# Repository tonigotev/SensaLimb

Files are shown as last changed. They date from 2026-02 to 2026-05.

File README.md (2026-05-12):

# SensaLimb

Smart arm prosthesis project.

## ML Model (Latest Recommended): Toro Ossaba Conv1D

Use this model family as the current default:

- Model family folder: `ML/models/conv1d_angle_toro_ossaba`
- Dataset folder (required): `ML/datasets/Toro Ossaba`
- Training script: `ML/train/train_conv1d_angle_toro_ossaba.py`

## 1) Install ML dependencies

From the repository root (PowerShell):

```powershell
python -m pip install --upgrade pip
python -m pip install -r requirements-ml.txt
```

## 2) Download and extract the Toro Ossaba dataset (required)

Dataset source:

- https://zenodo.org/records/7946782

Extract location must be exactly:

- `ML/datasets/Toro Ossaba`

Important extraction rule:

- After extraction, your `.txt` dataset files must be inside `ML/datasets/Toro Ossaba/...` (subject subfolders).
- Do **not** leave the files nested one level too deep (for example, avoid `ML/datasets/Toro Ossaba/Toro Ossaba/...`).

Quick check (PowerShell):

```powershell
Get-ChildItem "ML/datasets/Toro Ossaba" -Recurse -Filter *.txt | Select-Object -First 5 FullName
```

## 3) Install/extract the Toro Ossaba trained model files

If you received model files as a zip/archive, extract them into:

- `ML/models/conv1d_angle_toro_ossaba`

Expected model artifacts in the selected run folder:

- `model.keras`
- `model.tflite`
- `model_int8.tflite` (optional but recommended for embedded use)
- `meta.json`

Example expected path pattern:

- `ML/models/conv1d_angle_toro_ossaba/<run_name>/model.tflite`

If your extraction creates an extra folder level, move files so that the run folder directly contains `meta.json` and model files.

## 4) Run the model (inference/validation)

Pick your run folder (example):

```powershell
$MODEL_DIR = "ML/models/conv1d_angle_toro_ossaba/seed9_20260117_034451_884"
```

### A. Compare float vs int8 model outputs

```powershell
python ML/tools/compare_tflite_models.py --model-dir "$MODEL_DIR" --input-root "ML/datasets/Toro Ossaba" --samples 50
```

### B. Generate prediction-vs-true plots

```powershell
python ML/tools/plot_tflite_pred_vs_true.py --model-dir "$MODEL_DIR" --input-root "ML/datasets/Toro Ossaba" --samples 2000
```

Output images are saved in the same run folder:

- `pred_vs_true_float.png`
- `pred_vs_true_int8.png`

## 5) (Optional) Train a new Toro Ossaba model run

```powershell
python ML/train/train_conv1d_angle_toro_ossaba.py --use-file-split --movement all --emg-source filtered --angle-history-sec 0.1 --tflite-int8 --seed 9 --run-name seed9_new
```

This creates a new run folder under `ML/models/conv1d_angle_toro_ossaba`.

## Common setup mistakes

- Dataset extracted to wrong folder (must be `ML/datasets/Toro Ossaba`).
- Extra nested folder after extraction.
- Model archive extracted to wrong location.
- Missing `model.tflite` / `meta.json` in selected run folder.

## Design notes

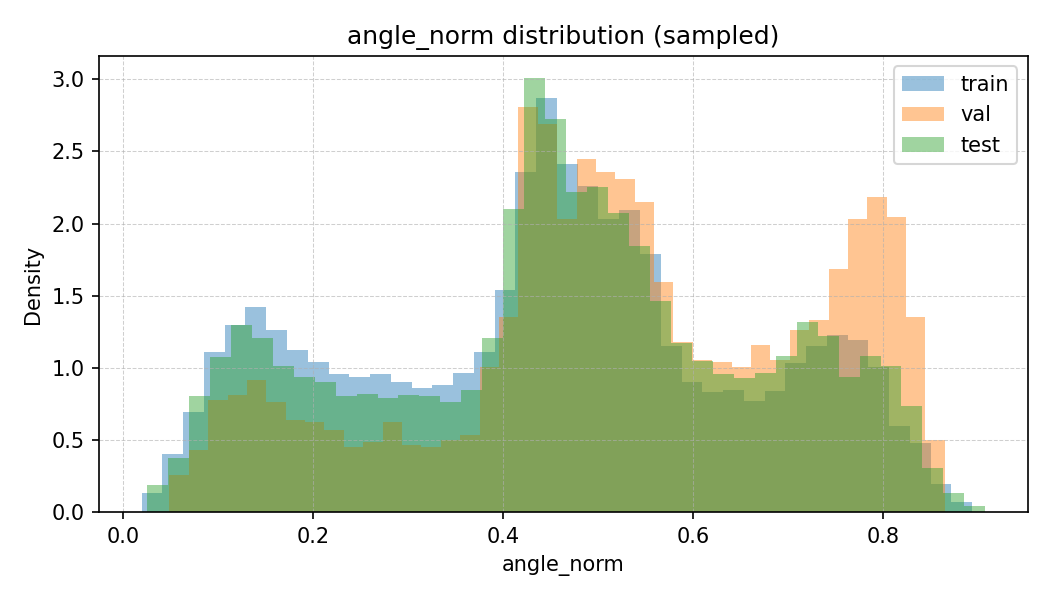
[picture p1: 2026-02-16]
ML/models/conv1d_angle_toro_ossaba/seed2_20260117_113150_814/angle_histograms.png

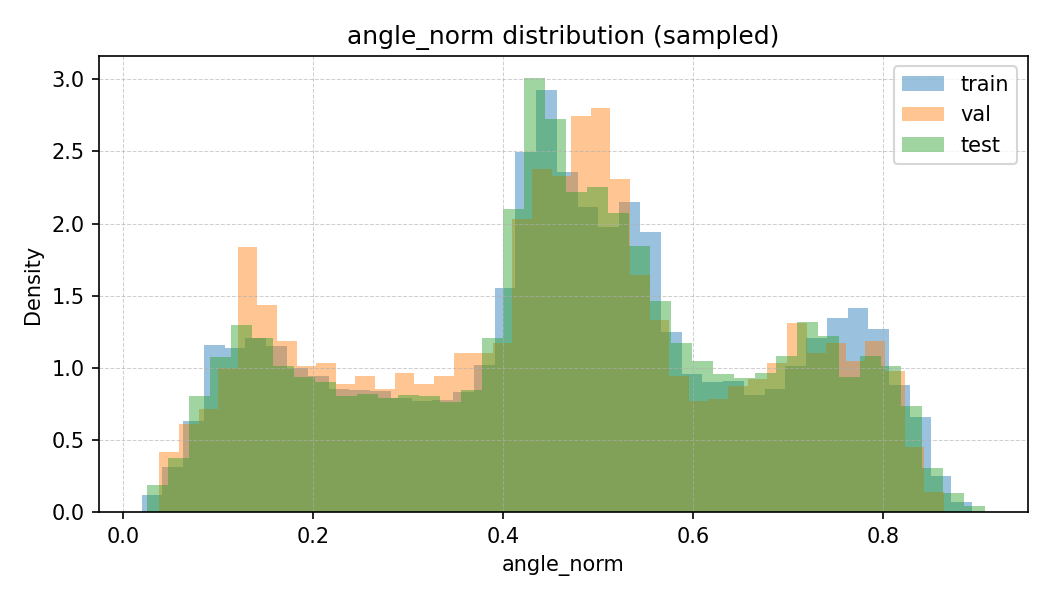
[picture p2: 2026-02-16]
ML/models/conv1d_angle_toro_ossaba/seed7_20260117_034451_861/angle_histograms.png

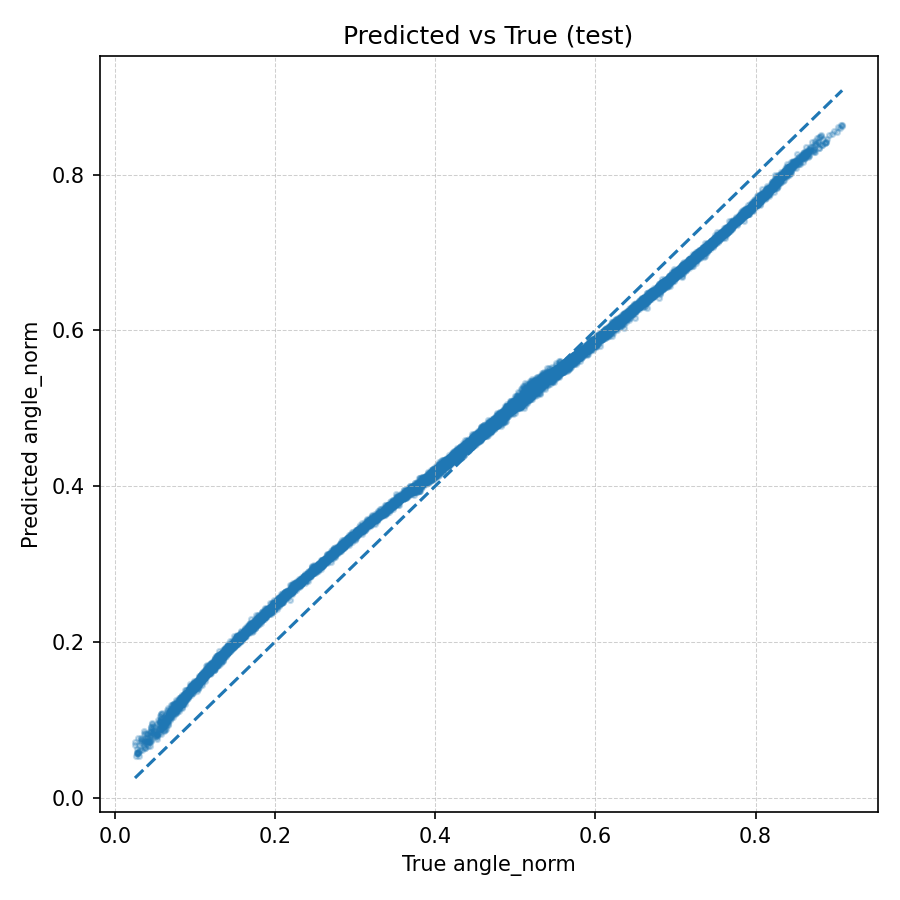
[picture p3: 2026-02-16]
ML/models/conv1d_angle_toro_ossaba/seed1_20260117_034451_773/pred_vs_true.png

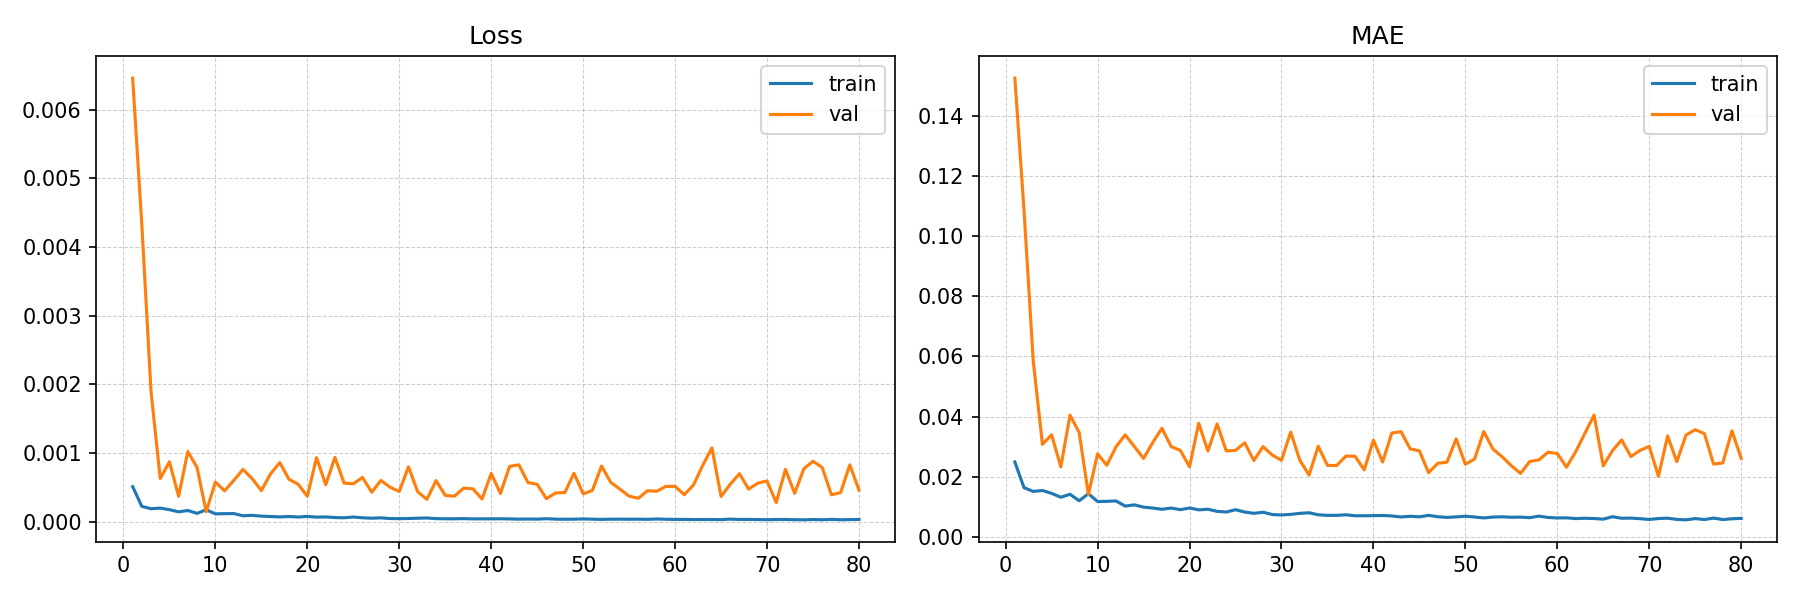
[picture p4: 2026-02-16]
ML/models/conv1d_angle_toro_ossaba/seed3_20260117_045953_614/training_curves.png

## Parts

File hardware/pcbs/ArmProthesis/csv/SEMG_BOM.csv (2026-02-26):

Reference | Value | Footprint | Qty | LCSC
VR1 | 100k | Potentiometer_THT:Potentiometer_Bourns_3296W_Vertical | 1 | C48084
U5 | LME49726MY | OP AMPS:LME49726MY | 1 | C128880
U4 | INA326 | Package_SO:MSOP-8_3x3mm_P0.65mm | 1 | C179740
U3 | LME49726MY | OP AMPS:LME49726MY | 1 | C128880
U2 | DNP | EMG:EMG_Snap_4mm | 1
U1 | DNP | EMG:EMG_Snap_4mm | 1
R12 | 10k | Resistor_SMD:R_0402_1005Metric | 1 | C25744
R11 | 1M | Resistor_SMD:R_0603_1608Metric | 1 | C22935
R10 | 1k | Resistor_SMD:R_0402_1005Metric | 1 | C106235
R9 | 10k | Resistor_SMD:R_0402_1005Metric | 1 | C25744
R8 | 1k | Resistor_SMD:R_0402_1005Metric | 1 | C106235
R6 | 249k | Resistor_SMD:R_0402_1005Metric | 1 | C226368
R5 | 1k | Resistor_SMD:R_0402_1005Metric | 1 | C106235
R4 | 1k | Resistor_SMD:R_0402_1005Metric | 1 | C106235
R3 | 2k | Resistor_SMD:R_0402_1005Metric | 1 | C60488
R2 | 10M | Resistor_SMD:R_0603_1608Metric | 1 | C7250
R1 | 10M | Resistor_SMD:R_0603_1608Metric | 1 | C7250
J4 | DNP | Connectors:DIN_Male_1PIN_1.5mm | 1
J3 | Conn_01x03_Pin | Connector_JST:JST_GH_SM03B-GHS-TB_1x03-1MP_P1.25mm_Horizontal | 1 | C514175
J2 | DNP | Connectors:DIN_Male_1PIN_1.5mm | 1
C11 | 1uF | Capacitor_SMD:C_0603_1608Metric | 1 | C15849
C10 | 1uF | Capacitor_SMD:C_0603_1608Metric | 1 | C15849
C9 | 1uF | Capacitor_SMD:C_0603_1608Metric | 1 | C15849
C8 | 1uF | Capacitor_SMD:C_0603_1608Metric | 1 | C15849
C7 | 1uF | Capacitor_SMD:C_0603_1608Metric | 1 | C15849
C6 | 1uF | Capacitor_SMD:C_0603_1608Metric | 1 | C15849
C3 | 330nF | Capacitor_SMD:C_0402_1005Metric | 1 | C47118439
C2 | DNP | Capacitor_SMD:C_0603_1608Metric | 1
C1 | 10uF | Capacitor_SMD:C_0402_1005Metric | 1 | C6119763

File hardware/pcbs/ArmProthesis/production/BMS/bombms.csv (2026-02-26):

Designator | Footprint | Quantity | Value | LCSC Part #
C1, C6, C7, C9 | 0603 | 4 | 1uF | C15849
C10 | 0402 | 1 | 1uF | C14445
C11 | 1206 | 1 | 10uF | C105197
C12 | 0402 | 1 | 100nF | C110251
C13, C14 | 0603 | 2 | 12pF | C346206
C3, C4, C5 | 0603 | 3 | 0.1uF | C14663
D1, D3, D4 | D_SOD-523 | 3 | 1N4148WT | C232841
D2 | 0603 | 1 | BLUE | C282129
J1 | AMASS_XT60PW-M_1x02_P7.20mm_Horizontal | 1 | XT60-M | C98732
J2 | AMASS_XT60PW-F_1x02_P7.20mm_Horizontal | 1 | XT60-F | C428722
J4 | JST_GH_SM03B-GHS-TB_1x03-1MP_P1.25mm_Horizontal | 1 | Conn_01x03 | C514175
Q1, Q2 | TRANS_BSC014N04LSIATMA1 | 2 | BSC014N04LSIATMA1 | C2934854
R1 | 2512 | 1 | 5m | C22385263
R10, R9 | 0603 | 2 | 1M | C22935
R11 | 0402 | 1 | 120k | C93945
R12 | 0402 | 1 | 1k | C11702
R13, R2, R3, R5, R6, R7, R8 | 0402 | 7 | 100 | C106232
R16 | 0402 | 1 | 10k | C60490
R17, R18, R19 | 0402 | 3 | 4.7k | C25900
R4 | 0402 | 1 | 100k | C25741
SW1, SW2, SW3 | SW_SPST_B3U-3000P | 3 | SW_Push | C963349
U2 | BQ76905RGRR | 1 | BQ76905RGRR | C22394458
U3, U4 | JST_GH_SM02B-GHS-TB_1x02-1MP_P1.25mm_Horizontal | 2 | JST-GH | C189893
U5 | PinHeader_2x05_P2.54mm_Horizontal | 1 | PIN-HEADER | C492433
U6 | TSSOP-20_4.4x6.5mm_P0.65mm | 1 | STM32C011F6Px | C5456198
Y1 | NX3215SA-32.768K-STD-MUA-8 | 1 | YXC X321532768KGD2SI | C620155

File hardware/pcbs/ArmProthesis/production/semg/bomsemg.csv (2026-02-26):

Designator | Footprint | Quantity | Value | LCSC Part #
C1 | 0402 | 1 | 10uF | C6119763
C10, C11, C6, C7, C8, C9 | 0603 | 6 | 1uF | C15849
C2 | 0603 | 1 | DNP
C3 | 0402 | 1 | 330nF | C47118439
J1 | JST_GH_SM02B-GHS-TB_1x02-1MP_P1.25mm_Horizontal | 1 | Conn_01x02_Pin | C189893
J2 | DIN_Male_1PIN_1.5mm | 1 | DNP
J3 | JST_GH_SM03B-GHS-TB_1x03-1MP_P1.25mm_Horizontal | 1 | Conn_01x03_Pin | C514175
R1 | 0603 | 1 | 10M
R10, R4, R5, R8 | 0402 | 4 | 1k | C106235
R11 | 0603 | 1 | 1M | C22935
R12, R9 | 0402 | 2 | 10k | C25744
R2 | 0603 | 1 | 10M | C7250
R3 | 0402 | 1 | 2k | C60488
R6 | 0402 | 1 | 249k | C226368
U1, U2 | EMG_Snap_4mm | 2 | ~
U3, U5 | LME49726MY | 2 | LME49726MY | C128880
U4 | MSOP-8_3x3mm_P0.65mm | 1 | INA326 | C179740
VR1 | Potentiometer_Bourns_3296W_Vertical | 1 | 100k | C48084

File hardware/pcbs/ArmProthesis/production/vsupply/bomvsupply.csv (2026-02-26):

Designator | Footprint | Quantity | Value | LCSC Part #
C1, C2 | 0805 | 2 | 10uF | C16194907
C3 | 0603 | 1 | 1uF | C15849
J1 | JST_GH_SM03B-GHS-TB_1x03-1MP_P1.25mm_Horizontal | 1 | Conn_01x03 | C514175
J2 | JST_GH_SM02B-GHS-TB_1x02-1MP_P1.25mm_Horizontal | 1 | ~ | C189893
R1 | 0603 | 1 | 7.15k | C25980
R2 | 0603 | 1 | 1k | C21190
R3, R4 | 0402 | 2 | 10k | C25744
U2 | TO-263-5_TabPin3 | 1 | LT1963AEQ | C107286
U3 | SOIC-8_3.9x4.9mm_P1.27mm | 1 | OPA197xD | C1347124

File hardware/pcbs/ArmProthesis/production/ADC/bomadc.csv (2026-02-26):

Designator | Footprint | Quantity | Value | LCSC Part #
C11, C12, C2, C6 | 0402 | 4 | 1uF | C52923
C3 | 0603 | 1 | 10uF | C19702
C4, C8, C9 | 0402 | 3 | 0.1uF | C307331
C5 | 0402 | 1 | 0.1uF
C7 | 0603 | 1 | 10 µF | C19702
J2 | PinHeader_1x12_P2.54mm_Vertical | 1 | ~ | C725944
R1, R2, R3 | 0402 | 3 | 1k | C11702
R4, R5 | 0603 | 2 | 10k | C25804
SW1, SW2, SW3 | SW_SPDT_Shouhan_MSK12C02 | 3 | SW_Reed_SPDT | C431540
U1 | AD7606BSTZ | 1 | AD7606BSTZ | C398827
U2 | JST_GH_SM08B-GHS-TB_1x08-1MP_P1.25mm_Horizontal | 1 | ~ | C265111
U3, U4 | JST_SH_SM08B-SRSS-TB_1x08-1MP_P1.00mm_Horizontal | 2 | ~ | C160407
U5 | JST_GH_SM02B-GHS-TB_1x02-1MP_P1.25mm_Horizontal | 1 | ~ | C189893
VR1 | TLV70033DDCR | 1 | TLV70033DDCR | C11337

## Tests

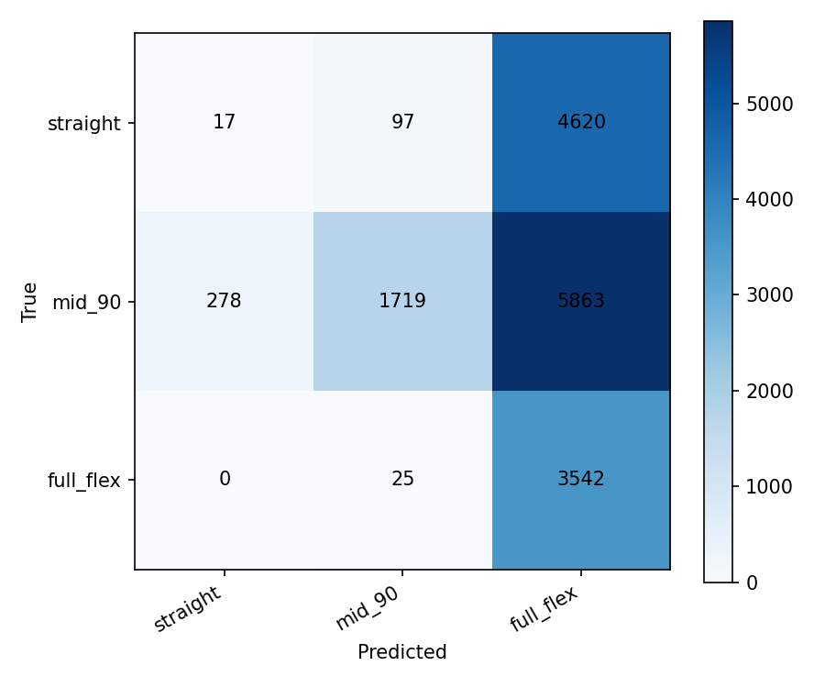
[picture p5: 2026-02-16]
ML/models/mlp_3class/confusion_matrix_test.png

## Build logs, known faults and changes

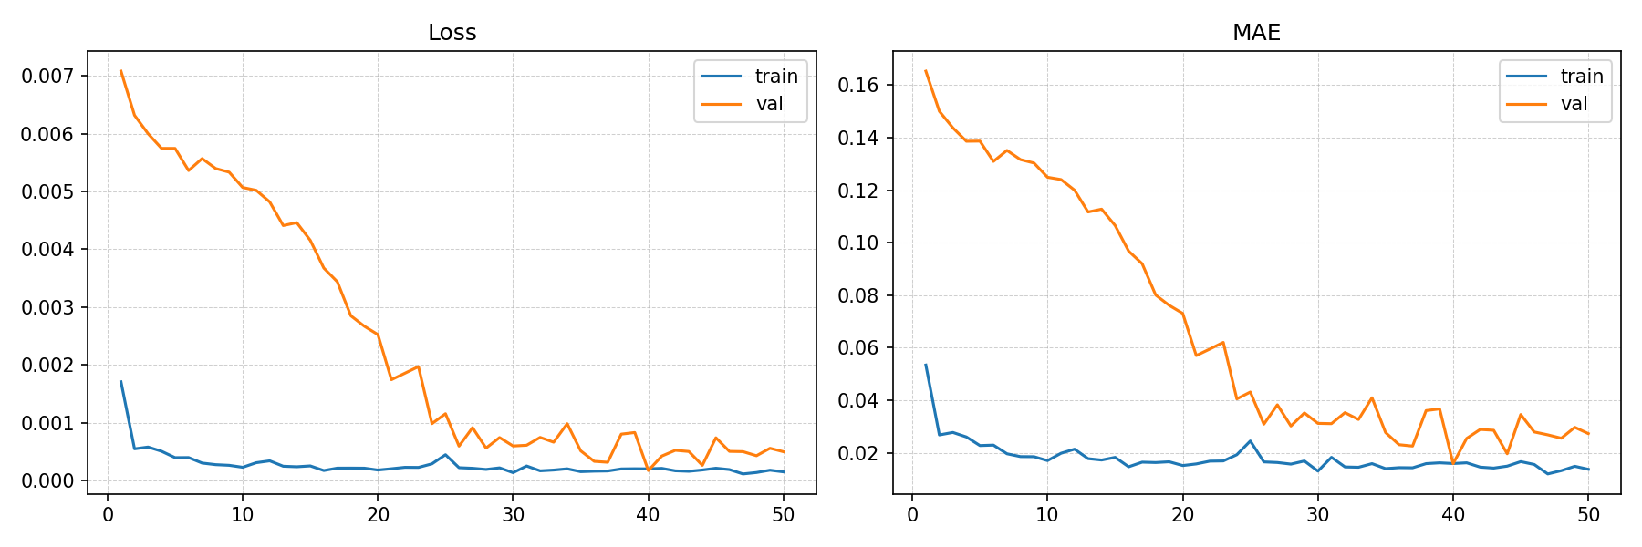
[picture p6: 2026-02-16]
ML/models/conv1d_angle_toro_ossaba/pred_vs_true_history_experiments/training_curves_0.01_history.png

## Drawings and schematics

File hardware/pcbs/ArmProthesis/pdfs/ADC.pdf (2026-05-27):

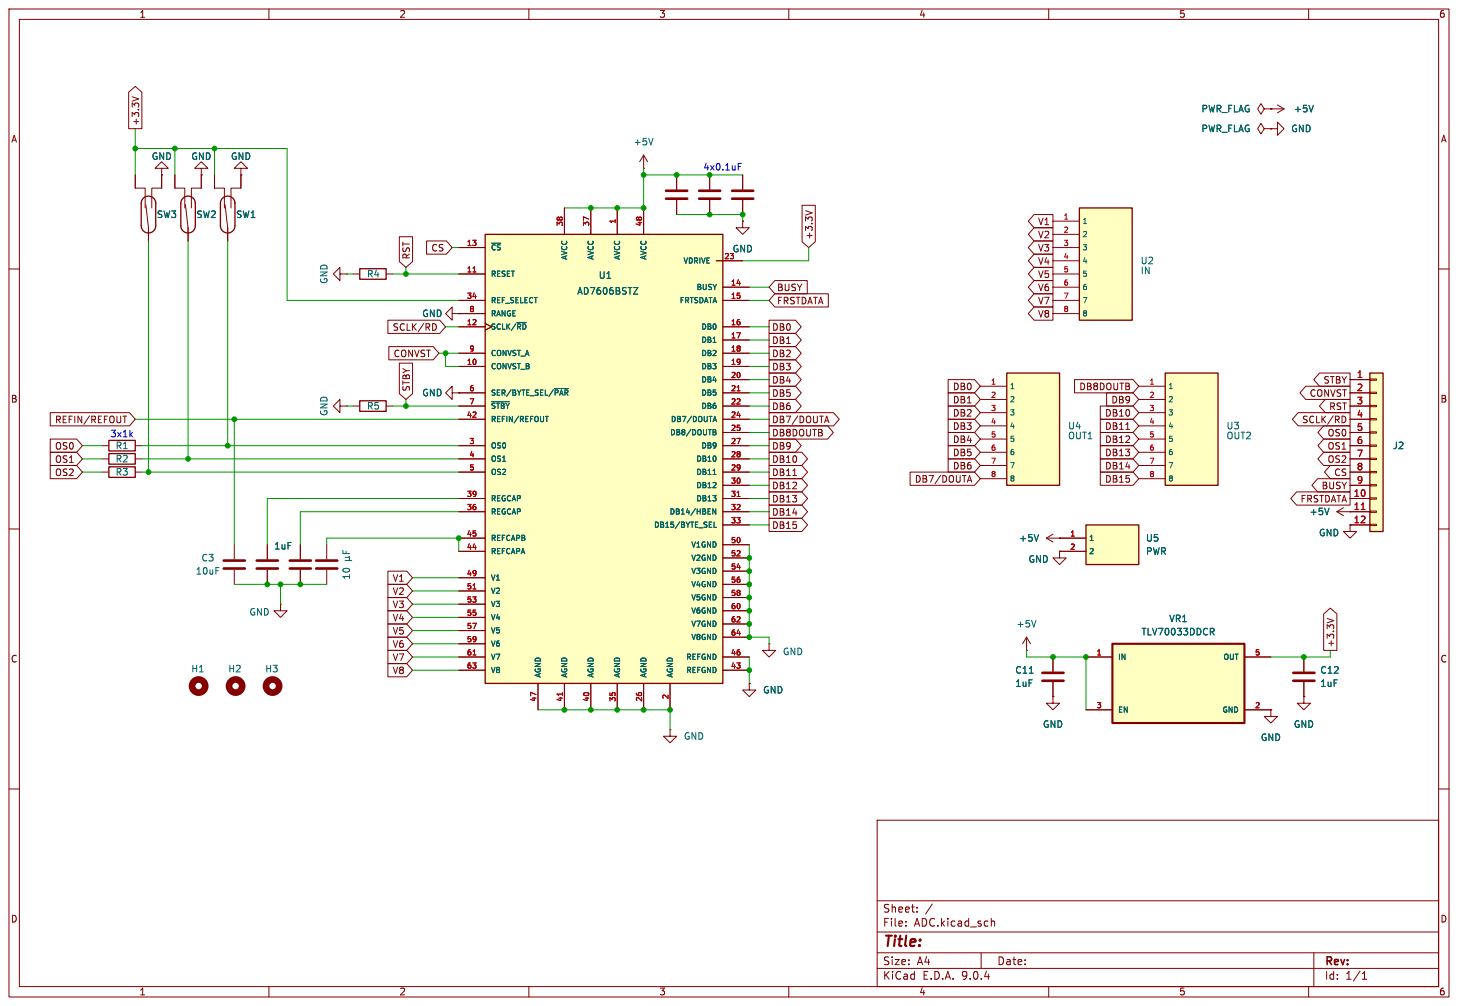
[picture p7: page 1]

1 AGND 35 AVCC 48 AGND 26 AGND

2 VDRIVE 23 BUSY 14 FRTSDATA 15 DB0 16 DB1 17 DB2 18 DB3 19 DB4 20 DB5 21 DB6 22 DB7/DOUTA 24 DB8/DOUTB 25 DB9 27 DB10 28 DB11 29 DB12 30 DB13 31 DB14/HBEN 32 DB15/BYTE_SEL 33 V1GND 50 V2GND 52 V3GND 54 V4GND 56 V5GND 58 V6GND 60 V7GND 62 V8GND 64 REFGND 46 REFGND 43 U1 AD7606BSTZ 10 þÿµF 1uF GND GND

2 VDRIVE 23 BUSY 14 FRTSDATA 15 DB0 16 DB1 17 DB2 18 DB3 19 DB4 20 DB5 21 DB6 22 DB7/DOUTA 24 DB8/DOUTB 25 DB9 27 DB10 28 DB11 29 DB12 30 DB13 31 DB14/HBEN 32 DB15/BYTE_SEL 33 V1GND 50 V2GND 52 V3GND 54 V4GND 56 V5GND 58 V6GND 60 V7GND 62 V8GND 64 REFGND 46 REFGND 43 GND GND

Id: 1/1 Title: File: ADC.kicad_sch Sheet: / GND

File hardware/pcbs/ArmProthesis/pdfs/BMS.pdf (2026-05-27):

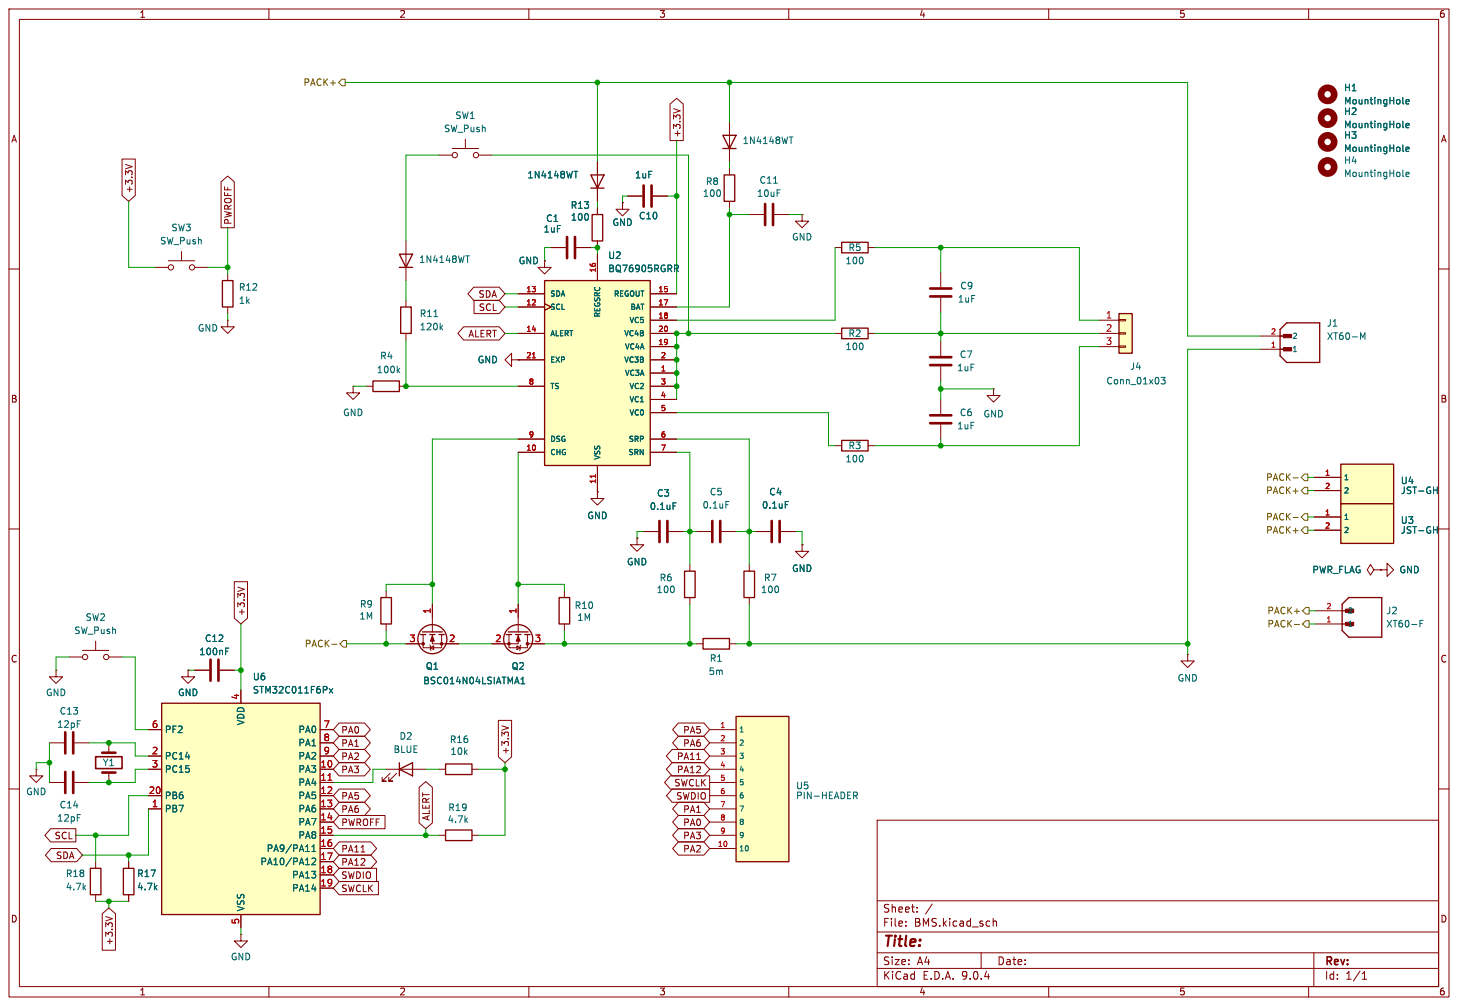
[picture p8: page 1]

Id: 1/1 Title: File: BMS.kicad_sch Sheet: / R9

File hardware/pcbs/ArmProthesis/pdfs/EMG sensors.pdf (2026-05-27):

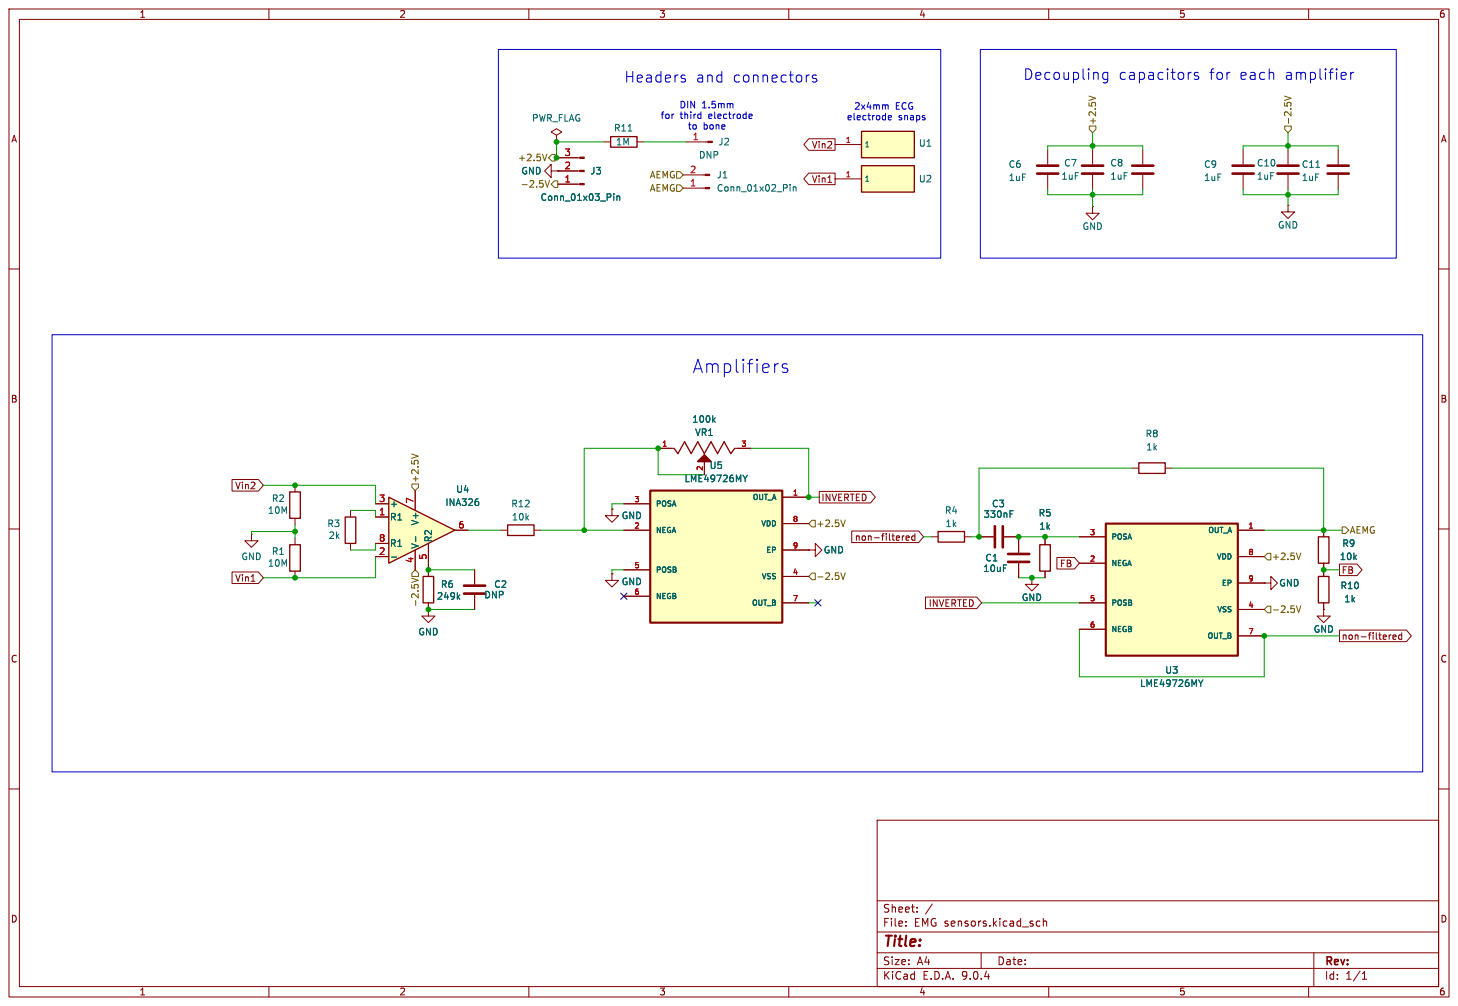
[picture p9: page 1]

Id: 1/1 Title: File: EMG sensors.kicad_sch Sheet: /

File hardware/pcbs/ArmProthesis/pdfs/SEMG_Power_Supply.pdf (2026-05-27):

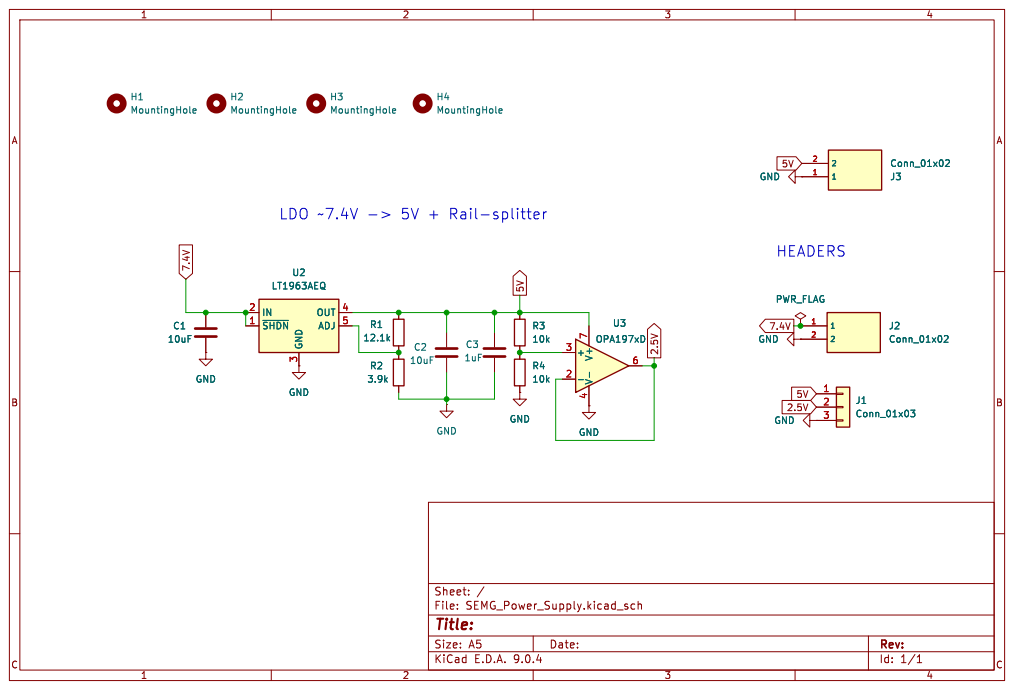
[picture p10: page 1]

Id: 1/1 Title: File: SEMG_Power_Supply.kicad_sch Sheet: /

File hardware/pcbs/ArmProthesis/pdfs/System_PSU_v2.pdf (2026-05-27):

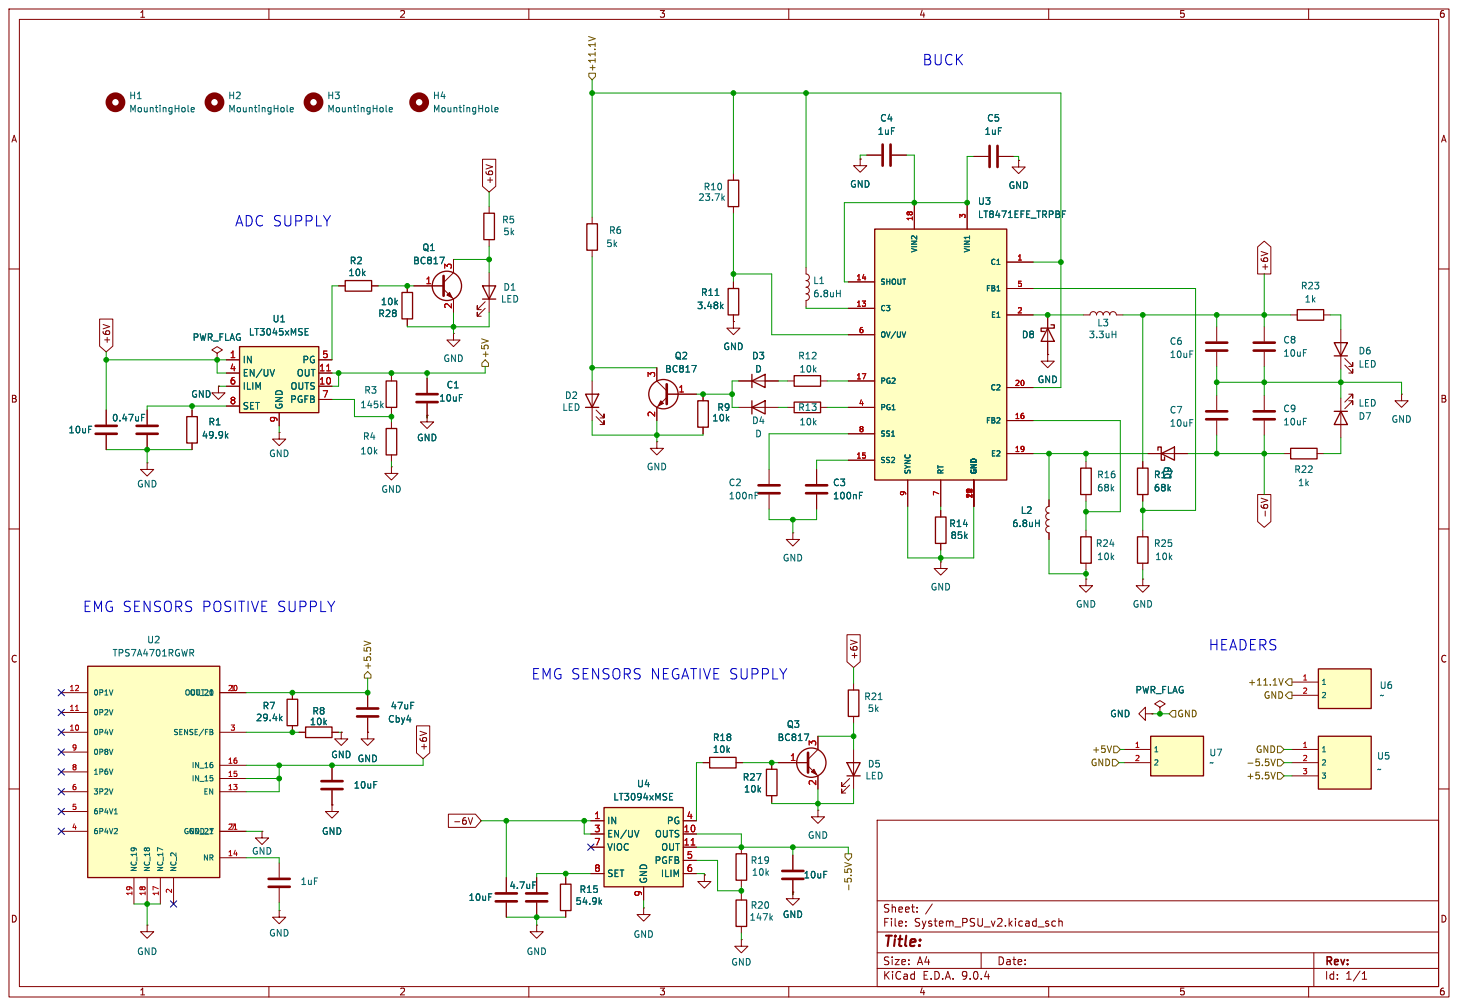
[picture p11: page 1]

9 PG 5 OUT 11 OUTS 10 PGFB 7 U1
LT3045xMSE
D8 GND GND

9 PG 5 OUT 11 OUTS 10 PGFB GND 7

EMG SENSORS POSITIVE SUPPLY

EMG SENSORS NEGATIVE SUPPLY

9 PG 4 OUTS 10 OUT 11 PGFB 5

Id: 1/1 Title: File: System_PSU_v2.kicad_sch Sheet: /

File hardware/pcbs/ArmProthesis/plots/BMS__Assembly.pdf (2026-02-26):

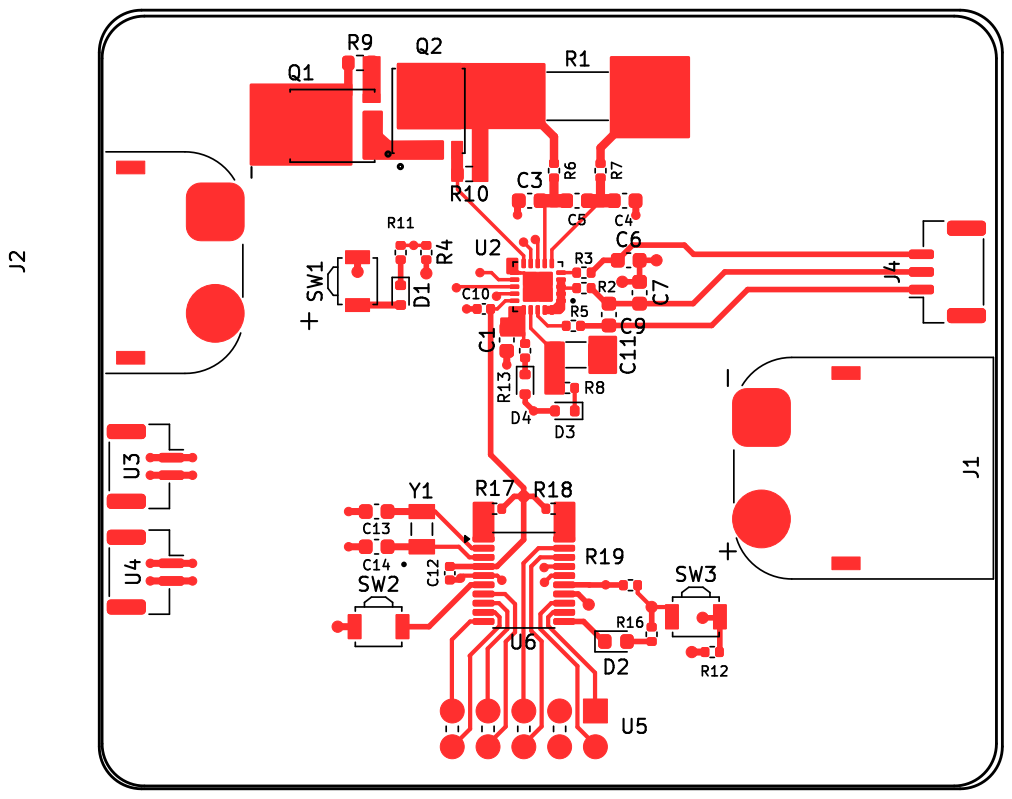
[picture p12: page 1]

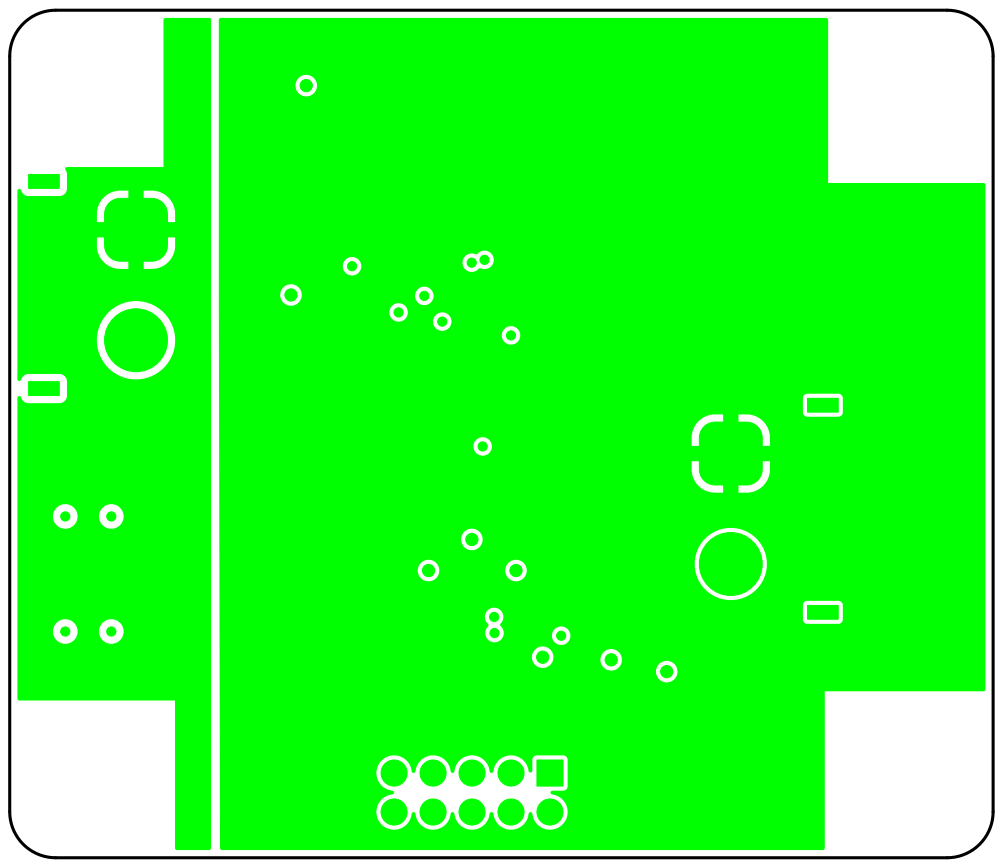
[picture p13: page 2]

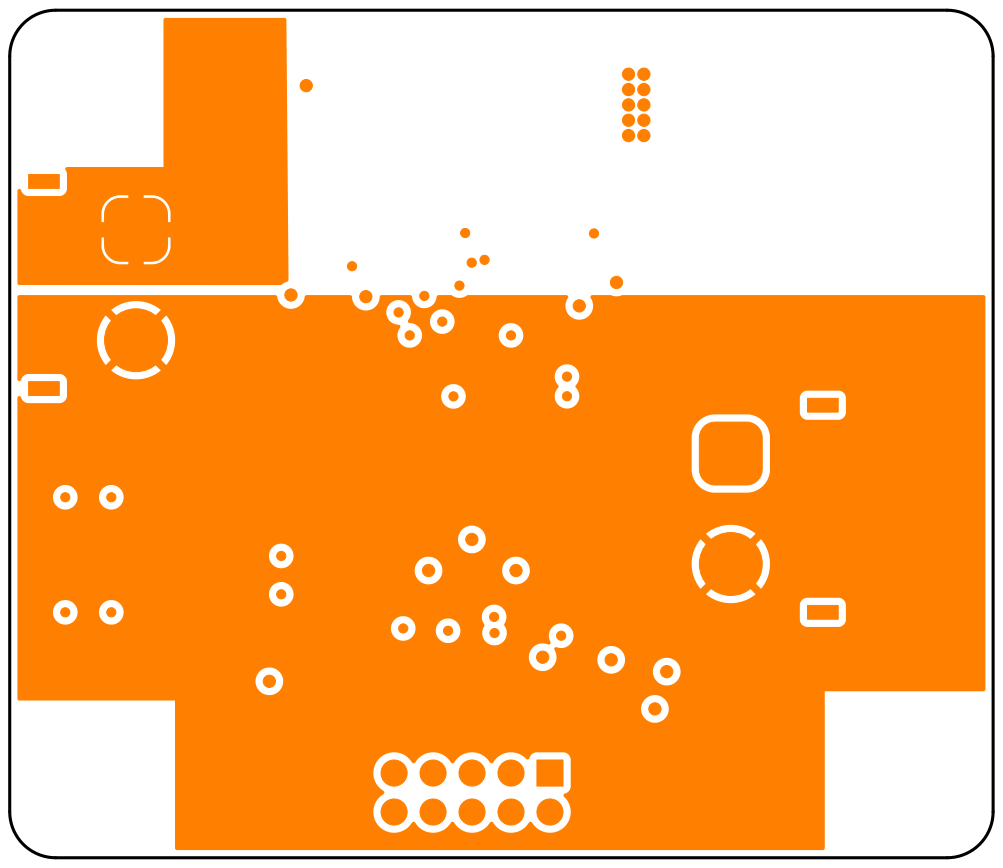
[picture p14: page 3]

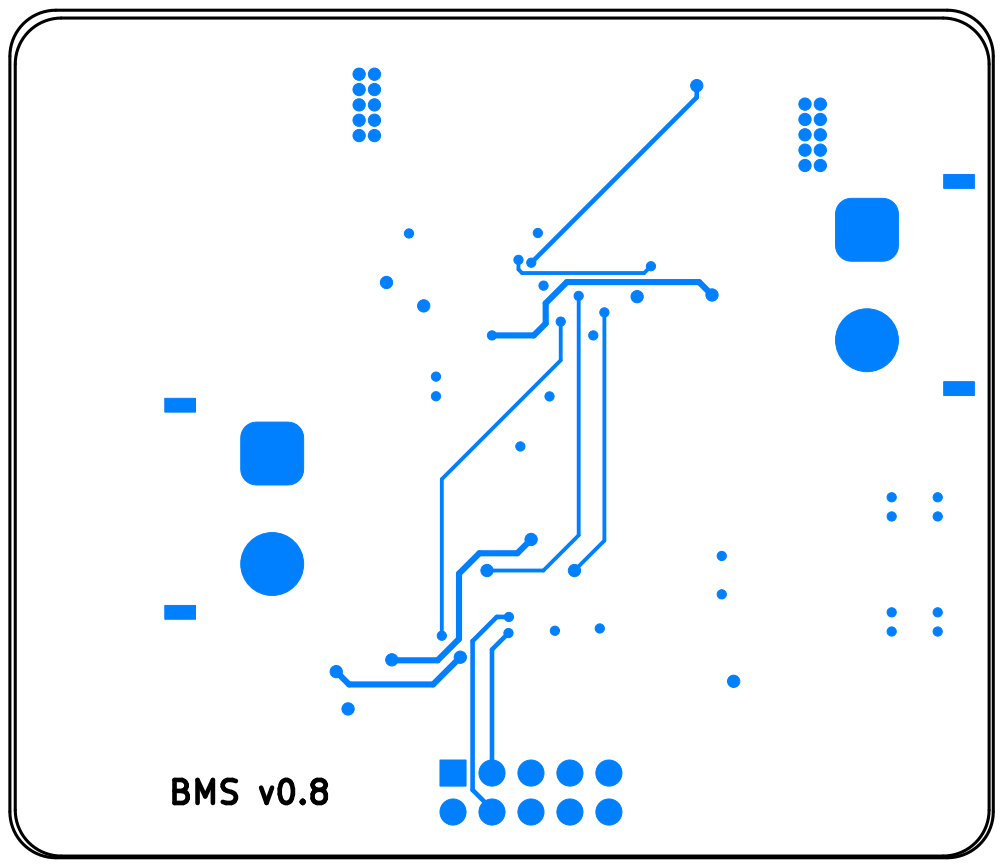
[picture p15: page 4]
BMS v0.8

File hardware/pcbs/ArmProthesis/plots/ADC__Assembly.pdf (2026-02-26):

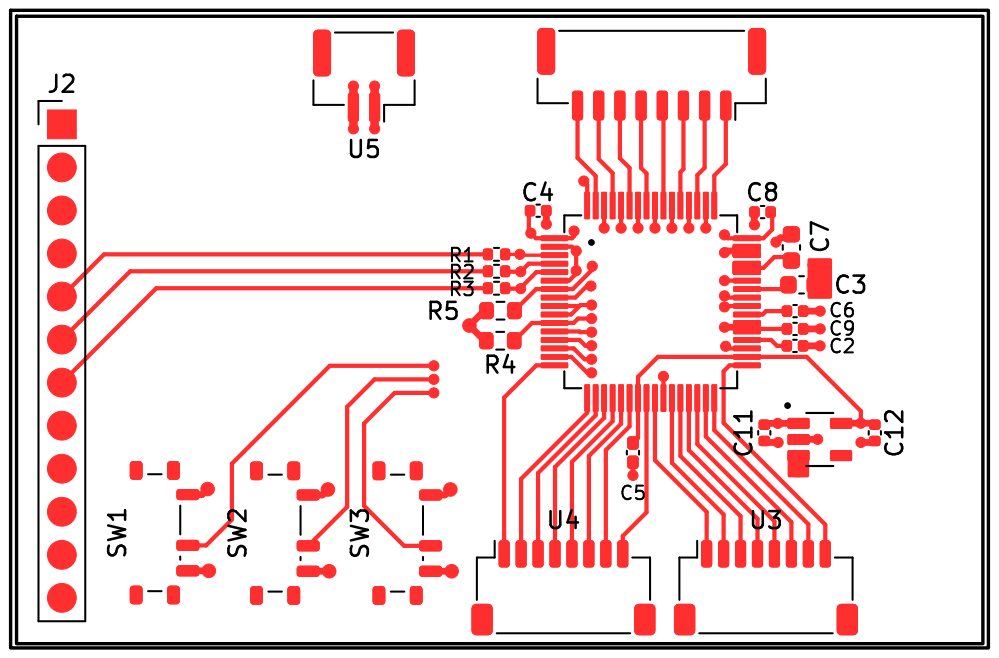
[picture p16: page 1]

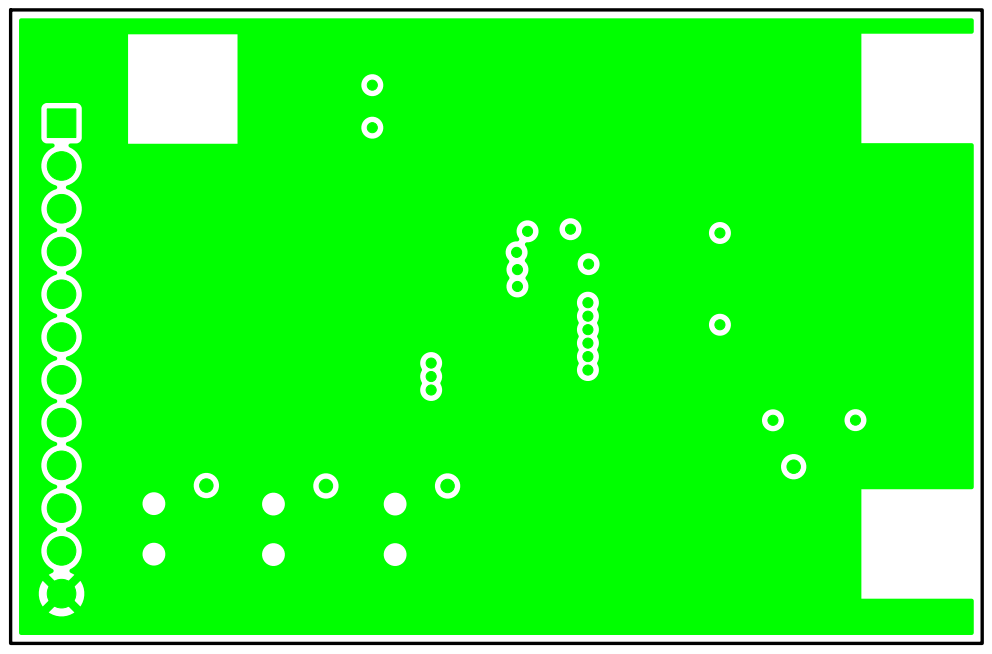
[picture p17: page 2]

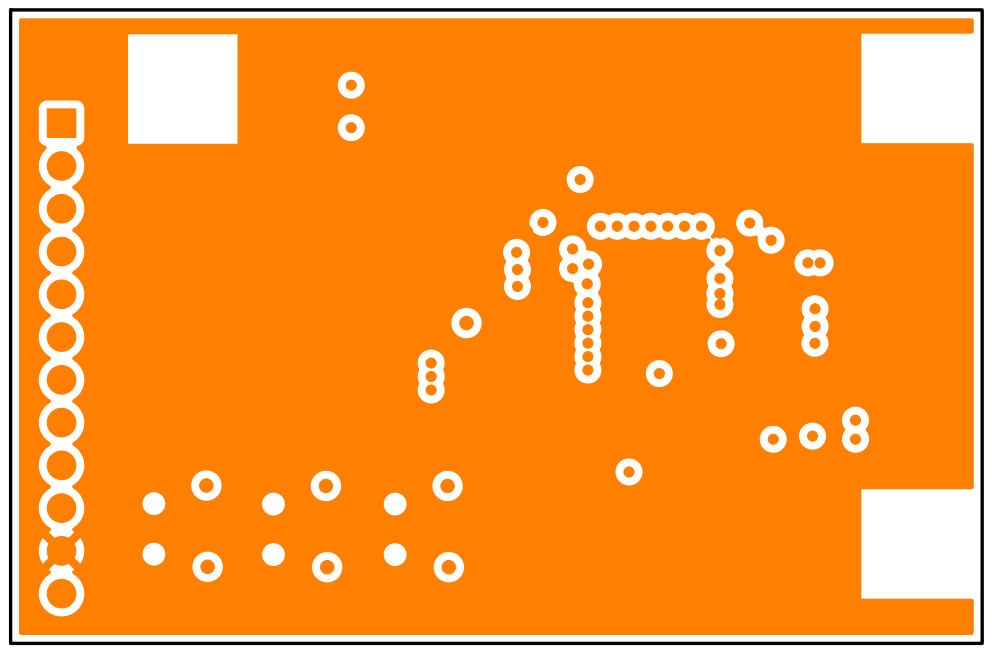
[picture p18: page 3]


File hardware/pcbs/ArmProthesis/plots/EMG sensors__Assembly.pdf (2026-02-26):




SensaLimb; sEMG



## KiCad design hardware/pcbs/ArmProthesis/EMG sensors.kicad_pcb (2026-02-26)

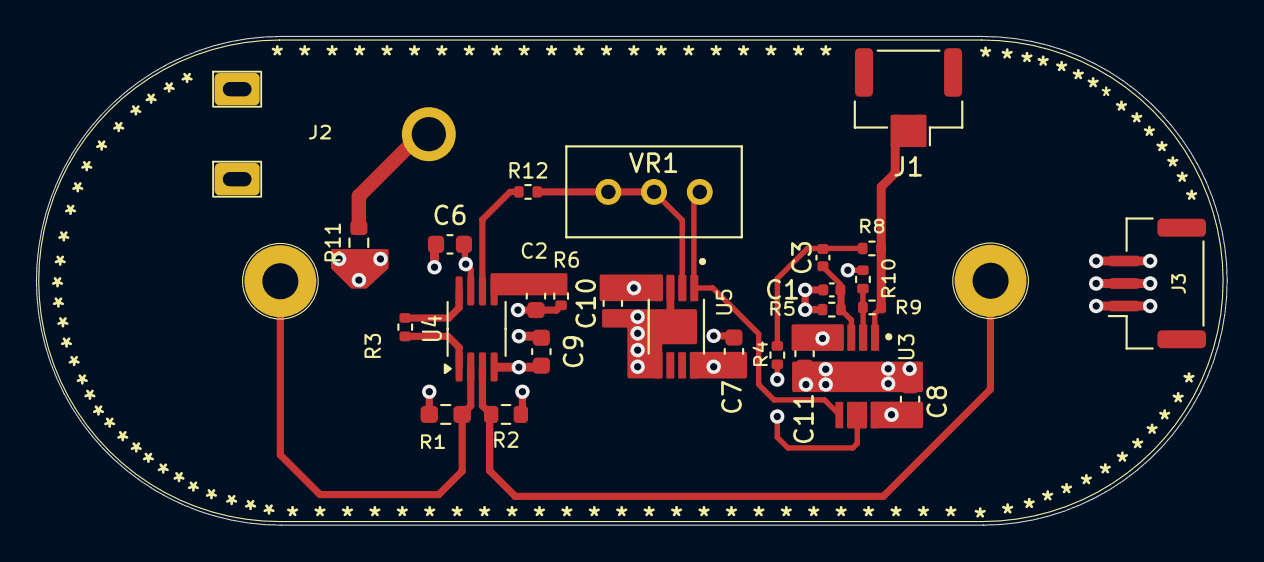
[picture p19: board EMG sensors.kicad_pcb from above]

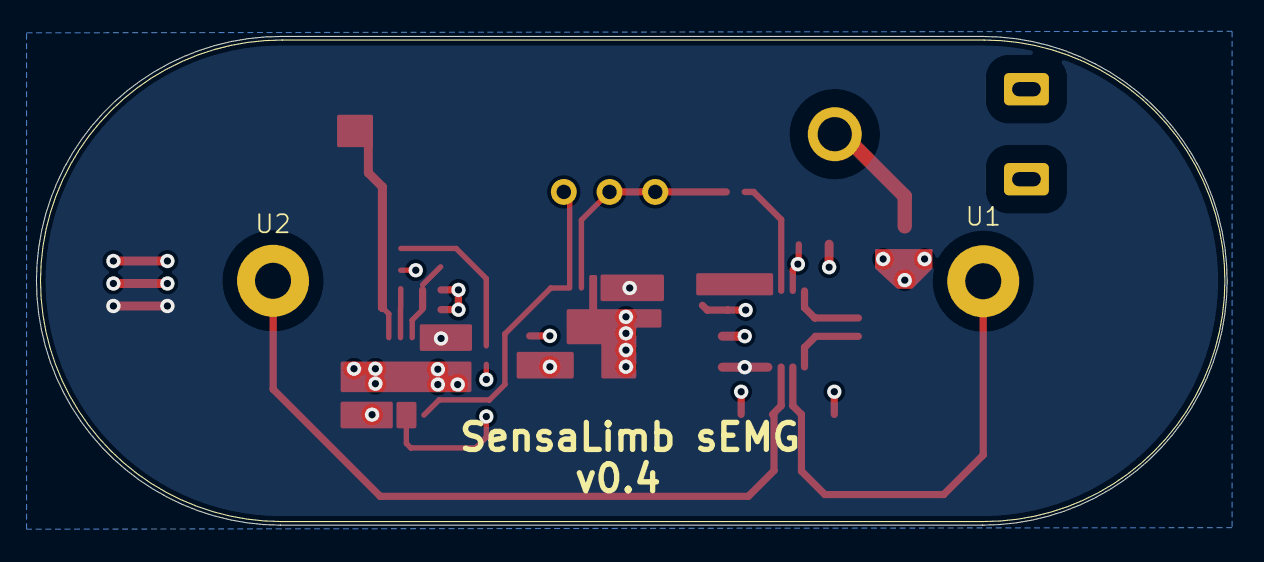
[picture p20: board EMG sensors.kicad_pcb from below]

Board: 4 copper layers, 66.2 x 27.1 mm, 29 parts (2 on the bottom side), 17 nets.

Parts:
C1: 10uF; C_0402_1005Metric
C2: DNP; C_0603_1608Metric
C3: 330nF; C_0402_1005Metric
C6, C7, C8, C9, C10, C11: 1uF; C_0603_1608Metric
J1: Conn_01x02_Pin; JST_GH_SM02B-GHS-TB_1x02-1MP_P1.25mm_Horizontal
J2: DNP; DIN_Male_1PIN_1.5mm
J3: Conn_01x03_Pin; JST_GH_SM03B-GHS-TB_1x03-1MP_P1.25mm_Horizontal
R1: 10M; R_0603_1608Metric_Pad0.98x0.95mm_HandSolder
R2: 10M; R_0603_1608Metric
R3: 2k; R_0402_1005Metric
R4, R5, R8, R10: 1k; R_0402_1005Metric
R6: 249k; R_0402_1005Metric
R9, R12: 10k; R_0402_1005Metric
R11: 1M; R_0603_1608Metric
U1, U2: EMG_Snap_4mm
U3, U5: LME49726MY
U4: INA326; MSOP-8_3x3mm_P0.65mm
VR1: 100k; Potentiometer_Bourns_3296W_Vertical

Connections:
/+2.5V: C6.1, C7.1, C8.1, J3.3, R11.1, U3.8 (VDD), U4.7 (V+), U5.8 (VDD)
/-2.5V: C9.1, C10.1, C11.1, J3.1, U3.4 (VSS), U4.4 (V-), U5.4 (VSS)
/AEMG: J1.1, J1.2, R8.1, R9.2, U3.1 (OUT_A)
FB: R9.1, R10.2, U3.2 (NEGA)
GND: C1.1, C2.1, C6.2, C7.2, C8.2, C9.2, C10.2, C11.2, J3.2, R1.1, R2.1, R5.1, R6.1, R10.1, U3.9 (EP), U5.3 (POSA), U5.5 (POSB), U5.9 (EP)
INVERTED: U3.5 (POSB), U5.1 (OUT_A), VR1.3
unnamed: C3.2, R4.2, R8.2
unnamed: J2.1, R11.2
unnamed: R3.1, U4.8 (R1)
unnamed: R3.2, U4.1 (R1)
unnamed: R12.1, U4.6
unnamed: C1.2, C3.1, R5.2, U3.3 (POSA)
unnamed: C2.2, R6.2, U4.5 (R2)
unnamed: R12.2, U5.2 (NEGA), VR1.1, VR1.2
Vin1: R1.2, U1.1, U4.2 (-)
Vin2: R2.2, U2.1, U4.3 (+)
non-filtered: R4.1, U3.6 (NEGB), U3.7 (OUT_B)

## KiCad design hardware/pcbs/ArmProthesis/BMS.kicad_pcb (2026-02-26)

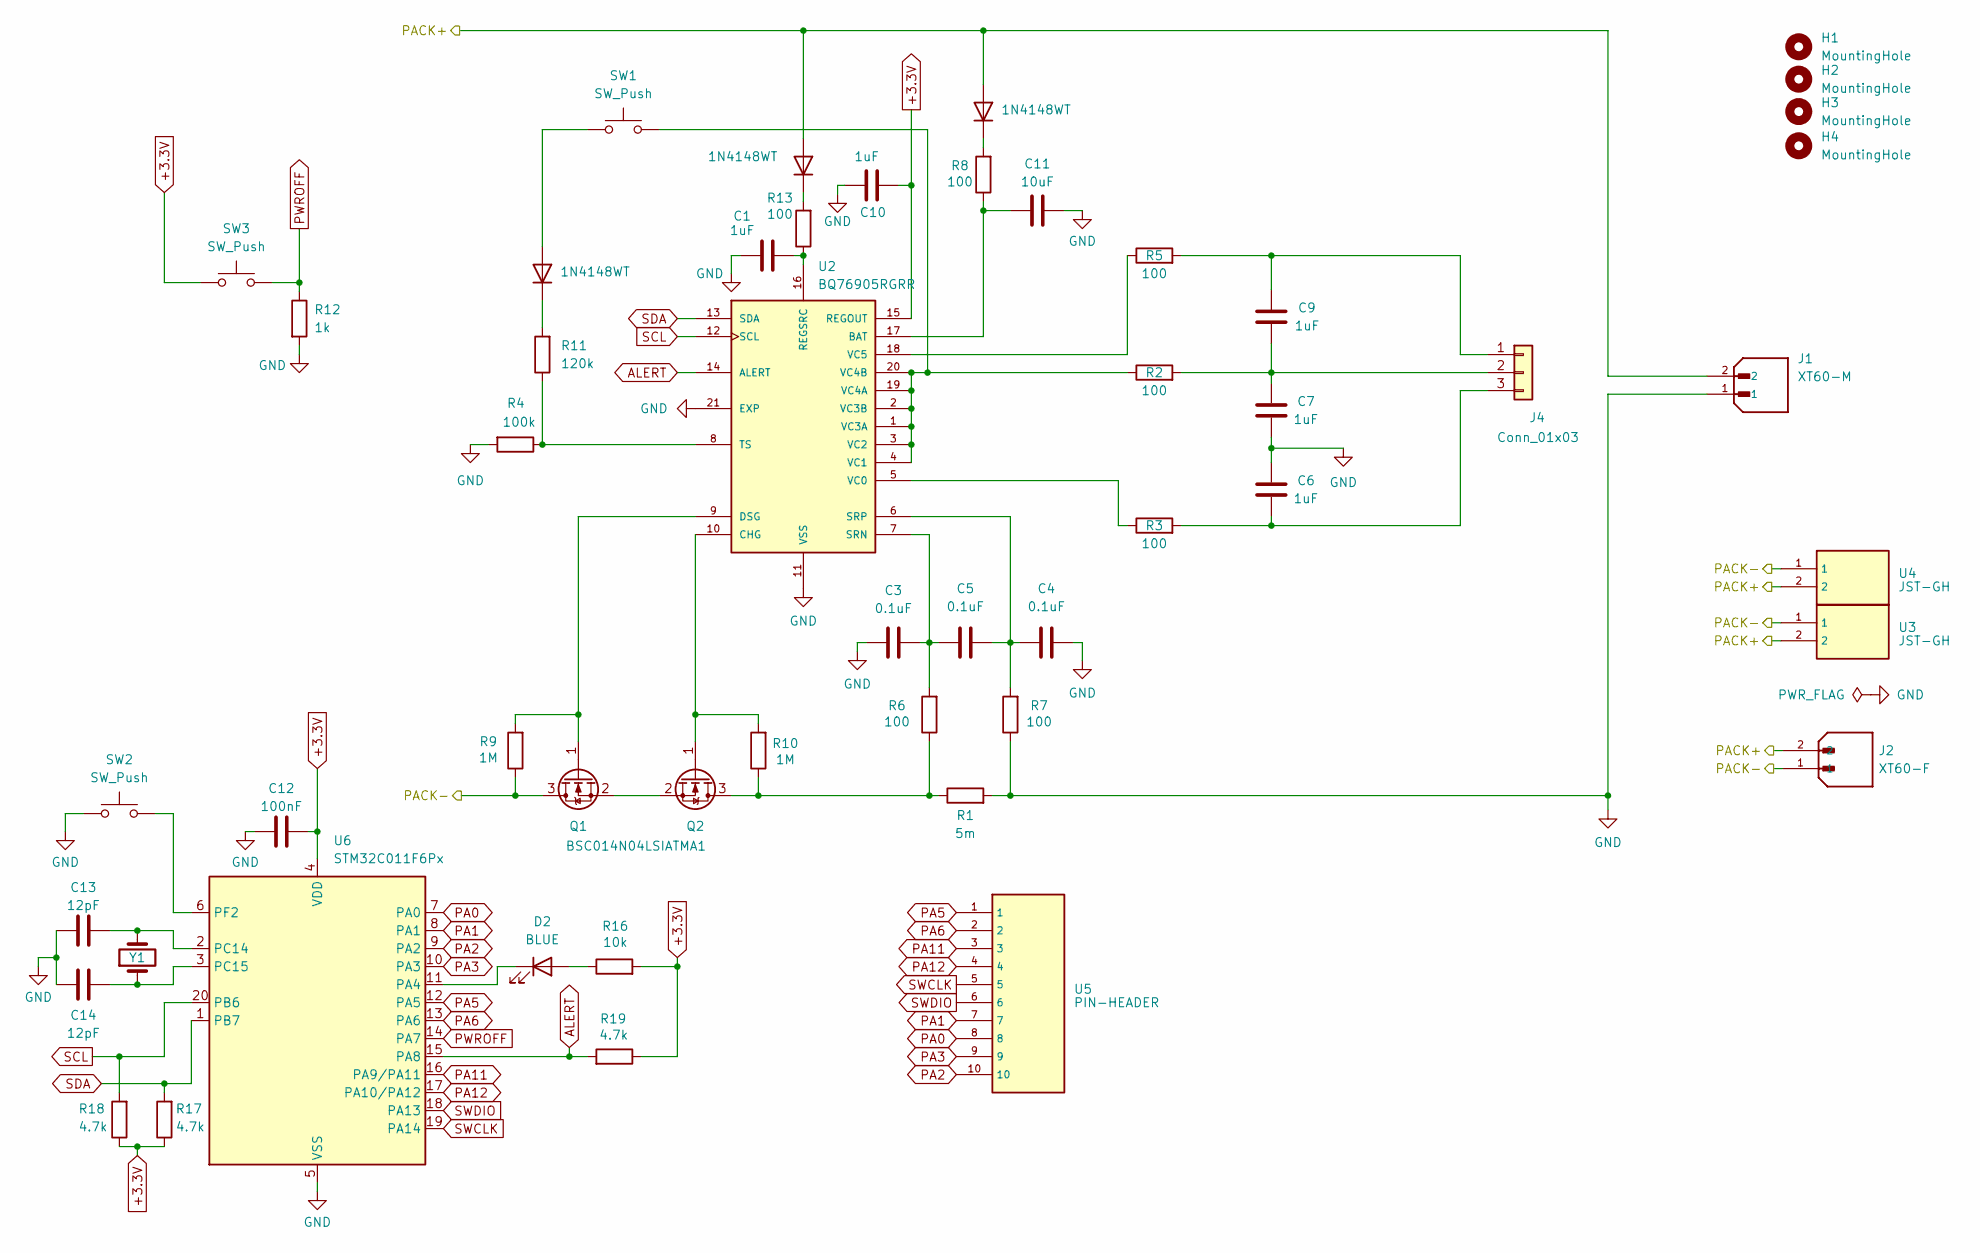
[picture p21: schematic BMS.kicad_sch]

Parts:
C1, C6, C7, C9: 1uF; C_0603_1608Metric; LCSC C15849
C3, C4, C5: 0.1uF; C_0603_1608Metric; LCSC C14663
C10: 1uF; C_0402_1005Metric; LCSC C14445
C11: 10uF; C_1206_3216Metric; LCSC C105197
C12: 100nF; C_0402_1005Metric; LCSC C110251
C13, C14: 12pF; C_0603_1608Metric; LCSC C346206
D1, D3, D4: 1N4148WT; D_SOD-523; LCSC C232841
D2: BLUE; D_0603_1608Metric; LCSC C282129
H1, H2, H3, H4: MountingHole; MountingHole_3.2mm_M3_DIN965
J1: XT60-M; AMASS_XT60PW-M_1x02_P7.20mm_Horizontal; PARTREV V1.2; LCSC C98732
J2: XT60-F; AMASS_XT60PW-F_1x02_P7.20mm_Horizontal; PARTREV V1.2; LCSC C428722
J4: Conn_01x03; JST_GH_SM03B-GHS-TB_1x03-1MP_P1.25mm_Horizontal; LCSC C514175
Q1, Q2: BSC014N04LSIATMA1; TRANS_BSC014N04LSIATMA1; LCSC C2934854
R1: 5m; R_2512_6332Metric; LCSC C22385263
R2, R3, R5, R6, R7, R8, R13: 100; R_0402_1005Metric; LCSC C106232
R4: 100k; R_0402_1005Metric; LCSC C25741
R9, R10: 1M; R_0603_1608Metric; LCSC C22935
R11: 120k; R_0402_1005Metric; LCSC C93945
R12: 1k; R_0402_1005Metric; LCSC C11702
R16: 10k; R_0402_1005Metric; LCSC C60490
R17, R18, R19: 4.7k; R_0402_1005Metric; LCSC C25900
SW1, SW2, SW3: SW_Push; SW_SPST_B3U-3000P; LCSC C963349
U2: BQ76905RGRR; PARTREV November 2023; LCSC C22394458
U3, U4: JST-GH; JST_GH_SM02B-GHS-TB_1x02-1MP_P1.25mm_Horizontal; LCSC C189893
U5: PIN-HEADER; PinHeader_2x05_P2.54mm_Horizontal; LCSC C492433
U6: STM32C011F6Px; TSSOP-20_4.4x6.5mm_P0.65mm; LCSC C5456198
Y1: YXC X321532768KGD2SI; NX3215SA-32.768K-STD-MUA-8; LCSC C620155

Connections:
+3.3V: C10.2, C12.1, R16.2, R17.1, R18.1, R19.1, SW3.1, U2.15 (REGOUT), U6.4 (VDD)
/PACK+: D3.2 (A), D4.2 (A), J1.2, J2.2, U3.2, U4.2
/PACK-: J2.1, Q1.3 (D), R9.1, U3.1, U4.1
ALERT: R19.2, U2.14 (ALERT), U6.15 (PA8)
GND: C1.1, C3.1, C4.1, C6.1, C7.2, C10.1, C11.1, C12.2, C13.2, C14.2, J1.1, R1.2, R4.2, R7.1, R12.2, SW2.1, U2.11 (VSS), U2.21 (EXP), U6.5 (VSS)
unnamed: D1.2 (A), SW1.1
unnamed: D1.1 (K), R11.2
unnamed: D2.2 (A), R16.1
unnamed: D2.1 (K), U6.11 (PA4)
unnamed: D3.1 (K), R8.2
unnamed: D4.1 (K), R13.2
unnamed: C9.1, J4.1, R5.2
unnamed: C7.1, C9.2, J4.2, R2.2
unnamed: C6.2, J4.3, R3.2
unnamed: Q1.1 (G), R9.2, U2.9 (DSG)
unnamed: Q1.2 (S), Q2.2 (S)
unnamed: Q2.3 (D), R1.1, R6.1, R10.1
unnamed: Q2.1 (G), R10.2, U2.10 (CHG)
unnamed: C11.2, R8.1, U2.17 (BAT)
unnamed: C1.2, R13.1, U2.16 (REGSRC)
unnamed: C3.2, C5.1, R6.2, U2.7 (SRN)
unnamed: C4.2, C5.2, R7.2, U2.6 (SRP)
unnamed: R4.1, R11.1, U2.8 (TS)
unnamed: R3.1, U2.5 (VC0)
unnamed: R2.1, SW1.2, U2.1 (VC3A), U2.2 (VC3B), U2.3 (VC2), U2.4 (VC1), U2.19 (VC4A), U2.20 (VC4B)
unnamed: R5.1, U2.18 (VC5)
unnamed: C13.1, U6.2 (PC14), Y1.2
unnamed: C14.1, U6.3 (PC15), Y1.1
unnamed: SW2.2, U6.6 (PF2)
PA0: U5.8, U6.7 (PA0)
PA1: U5.7, U6.8 (PA1)
PA2: U5.10, U6.9 (PA2)
PA3: U5.9, U6.10 (PA3)
PA5: U5.1, U6.12 (PA5)
PA6: U5.2, U6.13 (PA6)
PA11: U5.3, U6.16 (PA9/PA11)
PA12: U5.4, U6.17 (PA10/PA12)
PWROFF: R12.1, SW3.2, U6.14 (PA7)
SCL: R18.2, U2.12 (SCL), U6.20 (PB6)
SDA: R17.2, U2.13 (SDA), U6.1 (PB7)
SWCLK: U5.5, U6.19 (PA14)
SWDIO: U5.6, U6.18 (PA13)

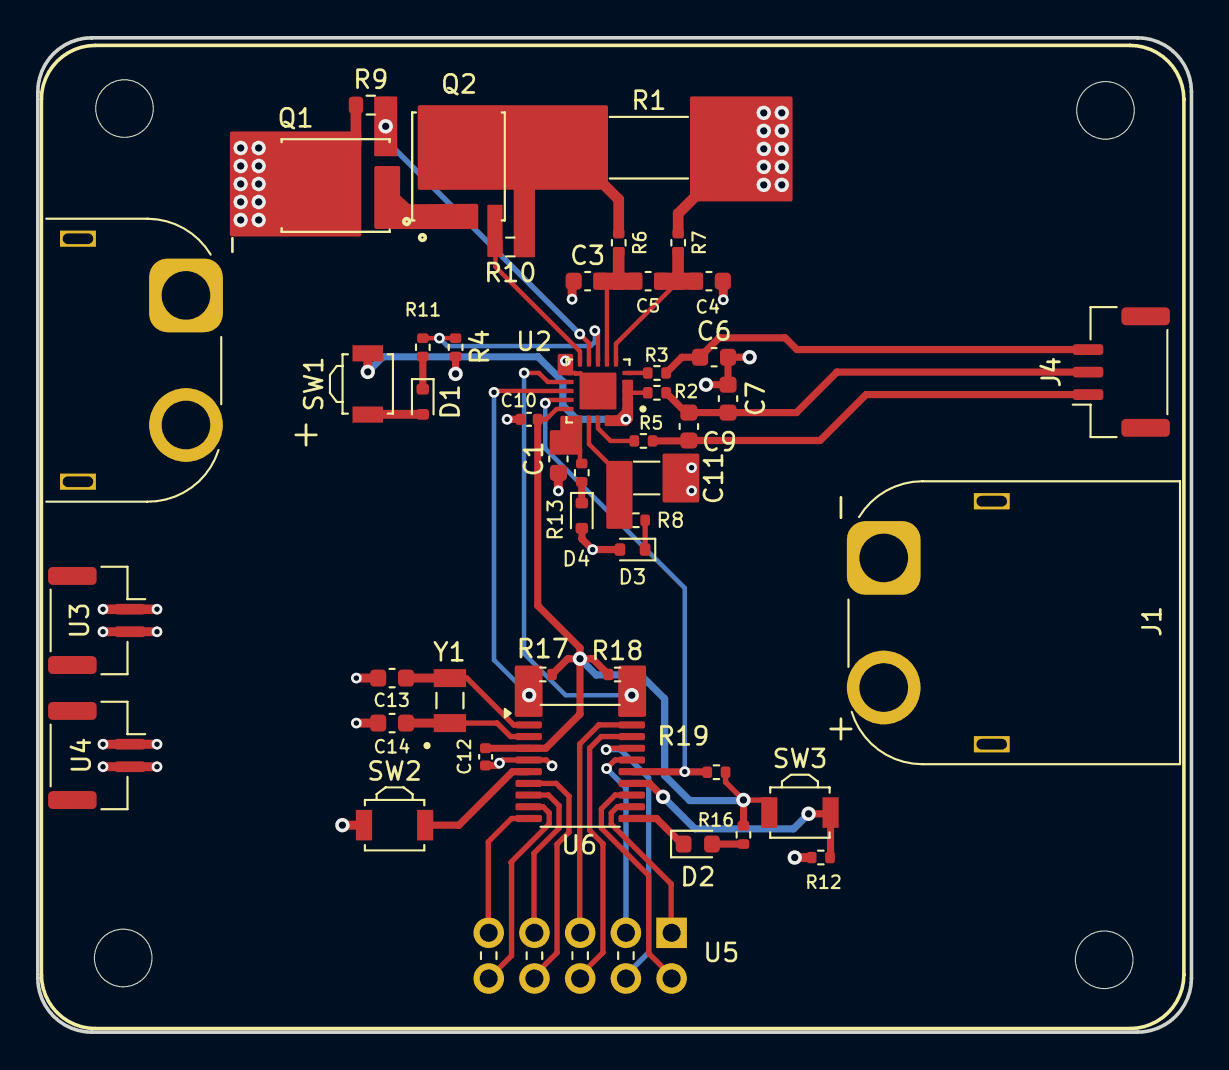
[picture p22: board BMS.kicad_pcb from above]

Board: 4 copper layers, 64.1 x 55.2 mm, 51 parts (0 on the bottom side), 42 nets.

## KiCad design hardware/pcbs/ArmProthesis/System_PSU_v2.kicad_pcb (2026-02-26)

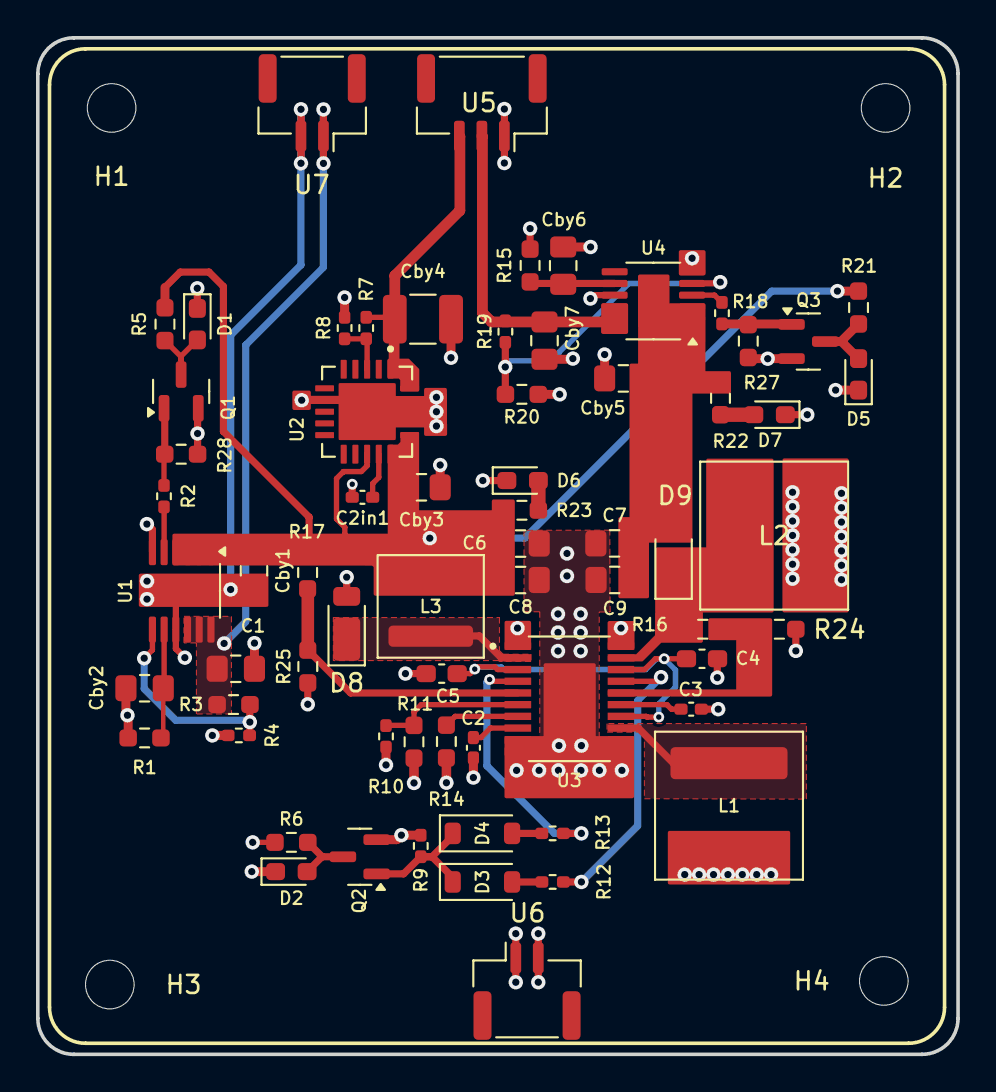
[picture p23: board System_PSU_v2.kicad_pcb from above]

Board: 4 copper layers, 51.1 x 56.5 mm, 70 parts (0 on the bottom side), 37 nets.

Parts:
C1, C6, C7, C8, C9: 10uF; C_0805_2012Metric_Pad1.18x1.45mm_HandSolder
C2, C3: 100nF; C_0402_1005Metric_Pad0.74x0.62mm_HandSolder
C2in1: 1uF; C_0402_1005Metric_Pad0.74x0.62mm_HandSolder
C4, C5: 1uF; C_0603_1608Metric_Pad1.08x0.95mm_HandSolder
Cby1, Cby3, Cby5, Cby7: 10uF; C_0805_2012Metric_Pad1.18x1.45mm_HandSolder
Cby2: 0.47uF; C_0805_2012Metric_Pad1.18x1.45mm_HandSolder
Cby4: 47uF; C_1210_3225Metric_Pad1.33x2.70mm_HandSolder
Cby6: 4.7uF; C_0805_2012Metric_Pad1.18x1.45mm_HandSolder
D1, D2, D5, D6, D7: LED; LED_0603_1608Metric_Pad1.05x0.95mm_HandSolder
D3, D4: D; D_SOD-123
D8: DFLS240L; D_PowerDI-123
D9: DFLS240; D_PowerDI-123
H1, H2, H3, H4: MountingHole; MountingHole_2.7mm_M2.5_DIN965
L1, L2: 6.8uH; L_Coilcraft_XAL7030-102
L3: 3.3uH; L_Coilcraft_XAL5030-XXX
Q1, Q2, Q3: BC817; SOT-23
R1: 49.9k; R_0603_1608Metric_Pad0.98x0.95mm_HandSolder
R2, R4, R8, R9, R12, R13, R18, R19: 10k; R_0402_1005Metric_Pad0.72x0.64mm_HandSolder
R3: 145k; R_0603_1608Metric_Pad0.98x0.95mm_HandSolder
R5, R6, R21: 5k; R_0603_1608Metric_Pad0.98x0.95mm_HandSolder
R7: 29.4k; R_0402_1005Metric_Pad0.72x0.64mm_HandSolder
R10: 23.7k; R_0402_1005Metric_Pad0.72x0.64mm_HandSolder
R11: 3.48k; R_0603_1608Metric_Pad0.98x0.95mm_HandSolder
R14: 85k; R_0603_1608Metric_Pad0.98x0.95mm_HandSolder
R15: 54.9k; R_0603_1608Metric_Pad0.98x0.95mm_HandSolder
R16, R17: 68k; R_0603_1608Metric_Pad0.98x0.95mm_HandSolder
R20: 147k; R_0603_1608Metric_Pad0.98x0.95mm_HandSolder
R22, R23: 1k; R_0603_1608Metric_Pad0.98x0.95mm_HandSolder
R24, R25, R27, R28: 10k; R_0603_1608Metric_Pad0.98x0.95mm_HandSolder
U1: LT3045xMSE; MSOP-12-1EP_3x4.039mm_P0.65mm_EP1.651x2.845mm
U2: TPS7A4701RGWR; QFN65P500X500X100-21N
U3: LT8471EFE_TRPBF; SOP65P640X120-21N
U4: LT3094xMSE; MSOP-12-1EP_3x4.039mm_P0.65mm_EP1.651x2.845mm
U5: JST_GH_SM03B-GHS-TB_1x03-1MP_P1.25mm_Horizontal
U6, U7: JST_GH_SM02B-GHS-TB_1x02-1MP_P1.25mm_Horizontal

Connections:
+6V: C6.1, C8.1, Cby1.1, Cby3.1, L3.2, R5.2, R17.1, R21.2, R23.1, U1.1 (IN), U1.2 (IN), U1.3 (IN), U1.4 (EN/UV), U2.13 (EN), U2.15 (IN_15), U2.16 (IN_16)
-6V: C7.2, C9.2, Cby5.1, D9.2 (A), R22.1, U4.1 (IN), U4.2 (IN), U4.3 (EN/UV), U4.13 (IN)
/+5.5V: Cby4.1, R7.1, U2.1 (OUT_1), U2.20 (OUT_20), U5.3
/+5V: C1.1, R3.2, U1.10 (OUTS), U1.11 (OUT), U1.12 (OUT), U7.1
/+11.1V: L1.1, R6.2, R10.2, U3.1 (C1), U3.20 (C2), U6.1
/-5.5V: Cby7.1, R19.1, U4.10 (OUTS), U4.11 (OUT), U4.12 (OUT), U5.2
GND: C1.2, C2.2, C2in1.2, C3.2, C4.1, C5.2, C6.2, C7.1, C8.2, C9.1, Cby1.2, Cby2.2, Cby3.2, Cby4.2, Cby5.2, Cby6.2, Cby7.2, D1.1 (K), D2.1 (K), D5.1 (K), D6.1 (K), D7.1 (K), D8.2 (A), L2.1, Q1.2 (E), Q2.2 (E), Q3.2 (E), R1.2, R4.1, R8.2, R9.2, R11.1, R14.2, R15.2, R20.2, R24.2, R25.2, R27.2, R28.2, U1.6 (ILIM), U1.9 (GND), U1.13 (GND), U2.7 (GND_7), U2.17 (NC_17), U2.18 (NC_18), U2.19 (NC_19), U2.21 (GND_21), U3.9 (SYNC), U3.10 (GND), U3.11 (GND), U3.12 (GND), U3.21 (GND), U4.6 (ILIM), U4.9 (GND), U5.1, U6.2, U7.2
unnamed: D1.2 (A), Q1.3 (C), R5.1
unnamed: D2.2 (A), Q2.3 (C), R6.1
unnamed: D3.2 (A), R12.2
unnamed: D3.1 (K), D4.1 (K), Q2.1 (B), R9.1
unnamed: D4.2 (A), R13.2
unnamed: D5.2 (A), Q3.3 (C), R21.1
unnamed: D6.2 (A), R23.2
unnamed: D7.2 (A), R22.2
unnamed: D8.1 (K), L3.1, U3.2 (E1)
unnamed: D9.1 (K), L2.2, R16.1, U3.19 (E2)
unnamed: Q1.1 (B), R2.2, R28.1
unnamed: Q3.1 (B), R18.2, R27.1
unnamed: R2.1, U1.5 (PG)
unnamed: R3.1, R4.2, U1.7 (PGFB)
unnamed: Cby2.1, R1.1, U1.8 (SET)
unnamed: C2in1.1, U2.14 (NR)
unnamed: R7.2, R8.1, U2.3 (SENSE/FB)
unnamed: L1.2, U3.13 (C3)
unnamed: R17.2, R25.1, U3.5 (FB1)
unnamed: R16.2, R24.1, U3.16 (FB2)
unnamed: R10.1, R11.2, U3.6 (OV/UV)
unnamed: R13.1, U3.4 (PG1)
unnamed: R12.1, U3.17 (PG2)
unnamed: R14.1, U3.7 (RT)
unnamed: C4.2, C5.1, U3.3 (VIN1), U3.14 (SHOUT), U3.18 (VIN2)
unnamed: C2.1, U3.8 (SS1)
unnamed: C3.1, U3.15 (SS2)
unnamed: R18.1, U4.4 (PG)
unnamed: R19.2, R20.1, U4.5 (PGFB)
unnamed: Cby6.1, R15.1, U4.8 (SET)

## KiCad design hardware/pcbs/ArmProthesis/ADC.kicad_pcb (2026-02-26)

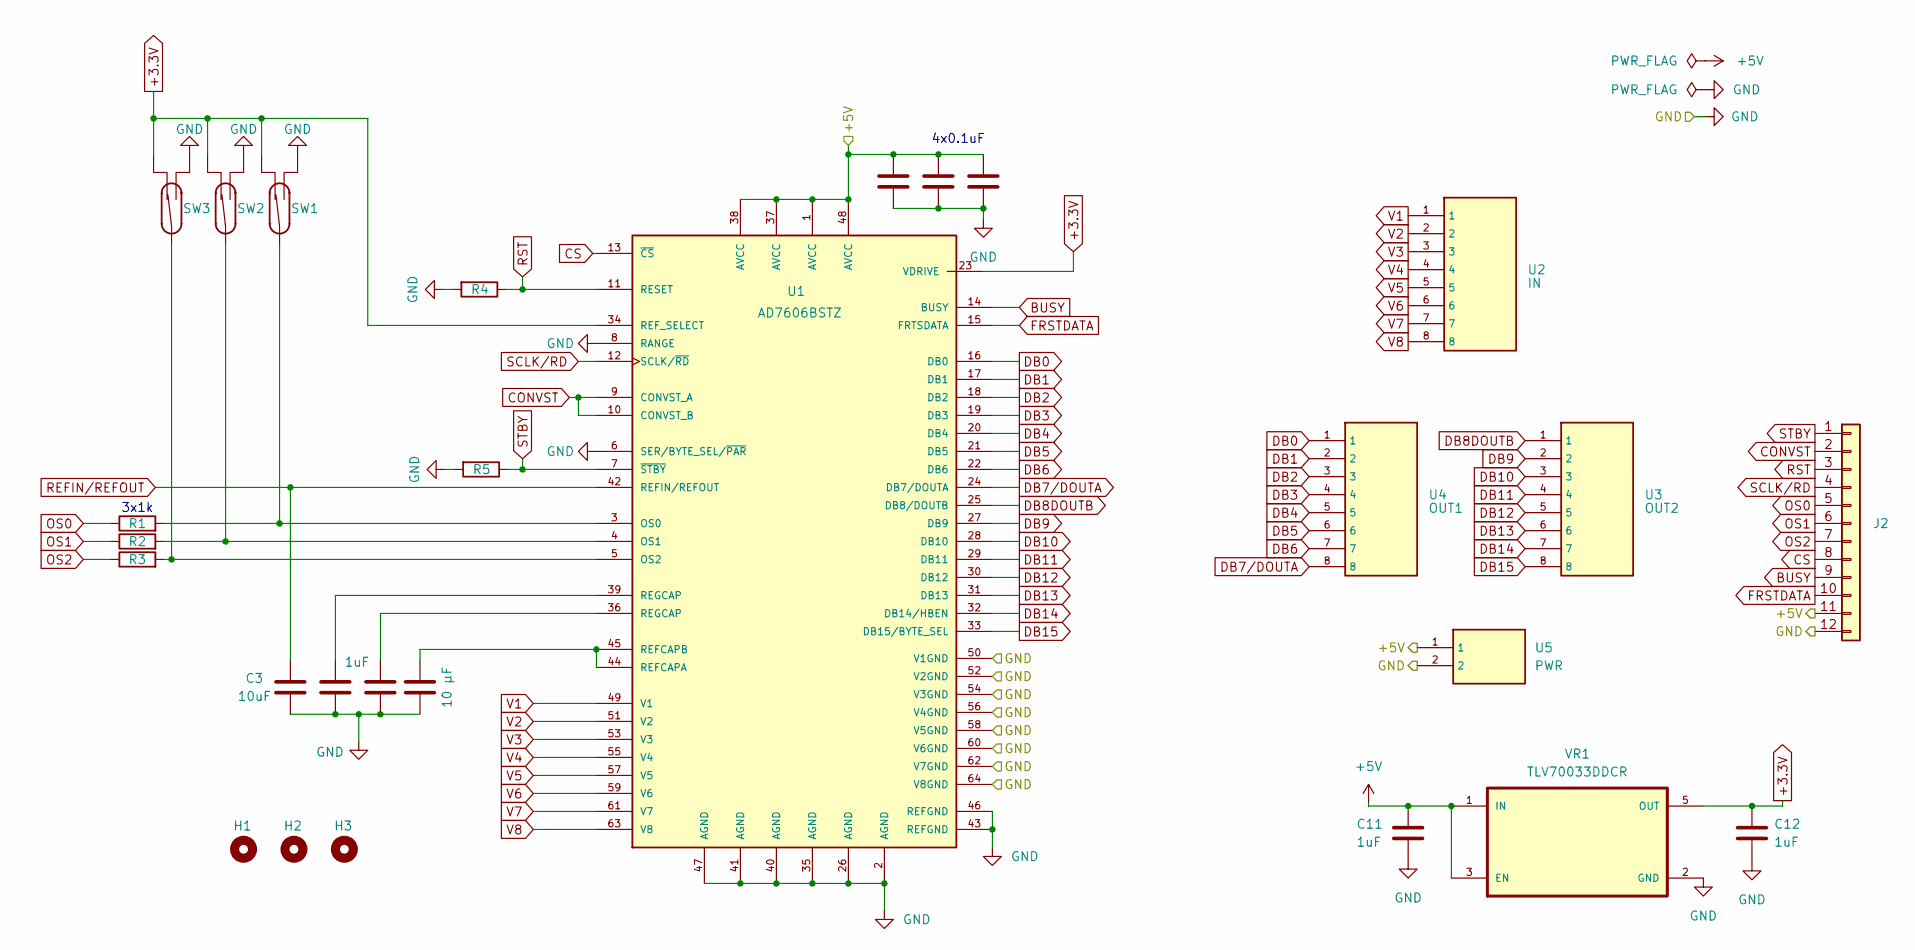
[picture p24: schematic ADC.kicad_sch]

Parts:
C2, C6, C11, C12: 1uF; C_0402_1005Metric; LCSC C52923
C3: 10uF; C_0603_1608Metric; LCSC C19702
C4, C8, C9: 0.1uF; C_0402_1005Metric; LCSC C307331
C7: 10 µF; C_0603_1608Metric; LCSC C19702
H1, H2, H3: MountingHole; MountingHole_2.7mm_M2.5
J2: SET; PinHeader_1x12_P2.54mm_Vertical; LCSC C725944
R1, R2, R3: 1k; R_0402_1005Metric; LCSC C11702
R4, R5: 10k; R_0603_1608Metric; LCSC C25804
SW1, SW2, SW3: SW_Reed_SPDT; SW_SPDT_Shouhan_MSK12C02; LCSC C431540
U1: AD7606BSTZ; LCSC C398827
U2: IN; JST_GH_SM08B-GHS-TB_1x08-1MP_P1.25mm_Horizontal; LCSC C265111
U3: OUT2; JST_SH_SM08B-SRSS-TB_1x08-1MP_P1.00mm_Horizontal; LCSC C160407
U4: OUT1; JST_SH_SM08B-SRSS-TB_1x08-1MP_P1.00mm_Horizontal; LCSC C160407
U5: PWR; JST_GH_SM02B-GHS-TB_1x02-1MP_P1.25mm_Horizontal; LCSC C189893
VR1: TLV70033DDCR; LCSC C11337

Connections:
+3.3V: C12.1, SW1.1, SW2.1, SW3.1, U1.23 (VDRIVE), U1.34 (REF_SELECT), VR1.5 (OUT); also elsewhere on the board
+5V: C4.2, C8.2, C9.2, C11.1, J2.11, U1.1 (AVCC), U1.37 (AVCC), U1.38 (AVCC), U1.48 (AVCC), U5.1, VR1.1 (IN), VR1.3 (EN)
BUSY: J2.9, U1.14 (BUSY)
CONVST: J2.2, U1.9 (CONVST_A), U1.10 (CONVST_B)
CS: J2.8, U1.13 (~CS)
DB0: U1.16 (DB0), U4.1
DB1: U1.17 (DB1), U4.2
DB2: U1.18 (DB2), U4.3
DB3: U1.19 (DB3), U4.4
DB4: U1.20 (DB4), U4.5
DB5: U1.21 (DB5), U4.6
DB6: U1.22 (DB6), U4.7
DB7/DOUTA: U1.24 (DB7/DOUTA), U4.8
DB8DOUTB: U1.25 (DB8/DOUTB), U3.1
DB9: U1.27 (DB9), U3.2
DB10: U1.28 (DB10), U3.3
DB11: U1.29 (DB11), U3.4
DB12: U1.30 (DB12), U3.5
DB13: U1.31 (DB13), U3.6
DB14: U1.32 (DB14/HBEN), U3.7
DB15: U1.33 (DB15/BYTE_SEL), U3.8
FRSTDATA: J2.10, U1.15 (FRTSDATA)
GND: C2.1, C3.1, C4.1, C6.1, C7.2, C8.1, C9.1, C11.2, C12.2, J2.12, R4.2, R5.2, SW1.3, SW2.3, SW3.3, U1.2 (AGND), U1.6 (SER/BYTE_SEL/~PAR), U1.8 (RANGE), U1.26 (AGND), U1.35 (AGND), U1.40 (AGND), U1.41 (AGND), U1.43 (REFGND), U1.46 (REFGND), U1.47 (AGND), U1.50 (V1GND), U1.52 (V2GND), U1.54 (V3GND), U1.56 (V4GND), U1.58 (V5GND), U1.60 (V6GND), U1.62 (V7GND), U1.64 (V8GND), U5.2, VR1.2 (GND); also elsewhere on the board
unnamed: C2.2, U1.36 (REGCAP)
unnamed: C6.2, U1.39 (REGCAP)
unnamed: R1.2, SW1.2, U1.3 (OS0)
unnamed: R2.2, SW2.2, U1.4 (OS1)
unnamed: R3.2, SW3.2, U1.5 (OS2)
unnamed: C7.1, U1.44 (REFCAPA), U1.45 (REFCAPB)
OS0: J2.5, R1.1
OS1: J2.6, R2.1
OS2: J2.7, R3.1
REFIN/REFOUT: C3.2, U1.42 (REFIN/REFOUT)
RST: J2.3, R4.1, U1.11 (RESET)
SCLK/RD: J2.4, U1.12 (SCLK/~RD)
STBY: J2.1, R5.1, U1.7 (~STBY)
V1: U1.49 (V1), U2.1
V2: U1.51 (V2), U2.2
V3: U1.53 (V3), U2.3
V4: U1.55 (V4), U2.4
V5: U1.57 (V5), U2.5
V6: U1.59 (V6), U2.6
V7: U1.61 (V7), U2.7
V8: U1.63 (V8), U2.8

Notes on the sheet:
3x1k
4x0.1uF

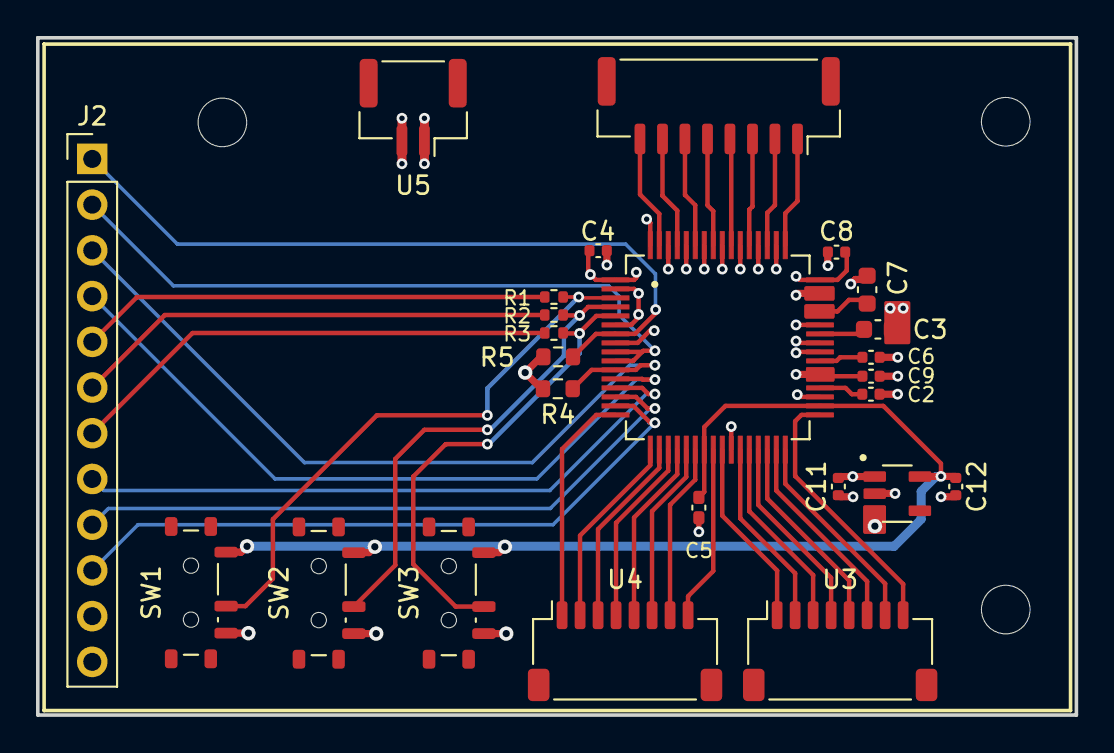
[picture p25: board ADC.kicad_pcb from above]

Board: 4 copper layers, 57.7 x 37.6 mm, 28 parts (0 on the bottom side), 44 nets.

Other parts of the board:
C5: 0.1uF; C_0402_1005Metric_Pad0.74x0.62mm_HandSolder

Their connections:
+3.3V: C5.2; also elsewhere on the board
GND: C5.1; also elsewhere on the board

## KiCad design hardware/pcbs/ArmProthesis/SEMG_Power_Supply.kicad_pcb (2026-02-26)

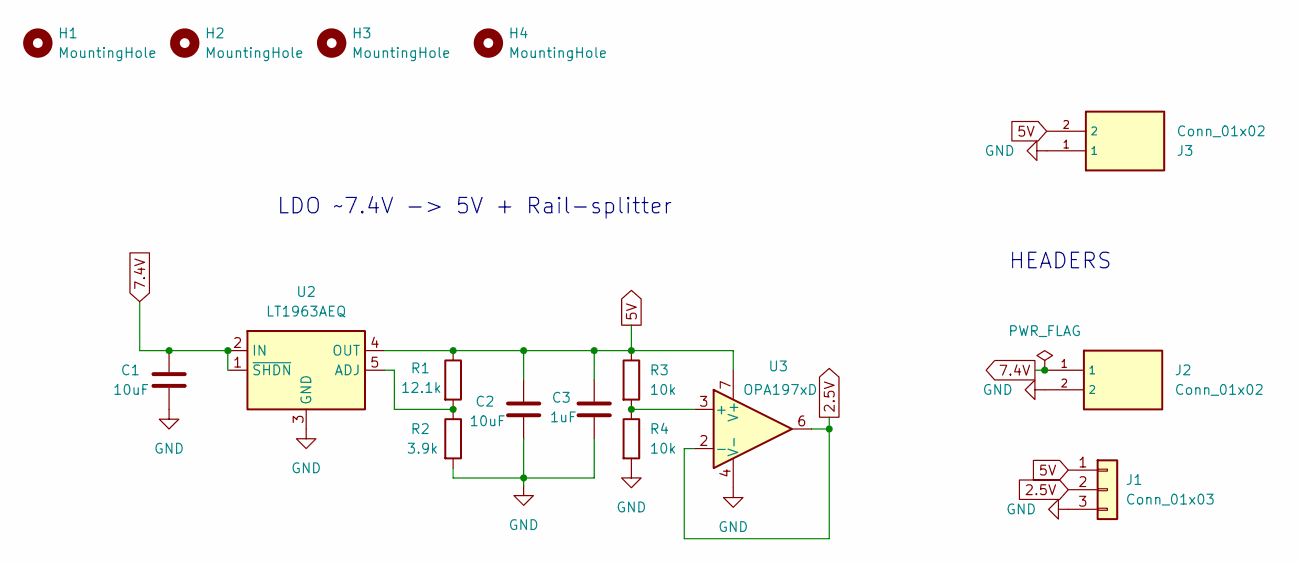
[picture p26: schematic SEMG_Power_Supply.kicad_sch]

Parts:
C1, C2: 10uF; C_0805_2012Metric; LCSC C92341
C3: 1uF; C_0603_1608Metric; LCSC C15849
H1, H2, H3, H4: MountingHole; MountingHole_2.7mm_M2.5_DIN965
J1: Conn_01x03; JST_GH_SM03B-GHS-TB_1x03-1MP_P1.25mm_Horizontal; LCSC C514175
J2, J3: Conn_01x02; JST_GH_SM02B-GHS-TB_1x02-1MP_P1.25mm_Horizontal; LCSC C189893
R1: 12.1k; R_0603_1608Metric; LCSC C22864
R2: 3.9k; R_0603_1608Metric; LCSC C114616
R3, R4: 10k; R_0402_1005Metric; LCSC C25744
U2: LT1963AEQ; TO-263-5_TabPin3; LCSC C107286
U3: OPA197xD; SOIC-8_3.9x4.9mm_P1.27mm; LCSC C1347124

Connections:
2.5V: J1.2, U3.2 (-), U3.6
5V: C2.1, C3.1, J1.1, J3.2, R1.1, R3.1, U2.4 (OUT), U3.7 (V+)
7.4V: C1.1, J2.1, U2.1 (~SHDN), U2.2 (IN)
GND: C1.2, C2.2, C3.2, J1.3, J2.2, J3.1, R2.2, R4.2, U2.3 (GND), U3.4 (V-)
unnamed: R1.2, R2.1, U2.5 (ADJ)
unnamed: R3.2, R4.1, U3.3 (+)

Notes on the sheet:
LDO ~7.4V -> 5V + Rail-splitter
HEADERS

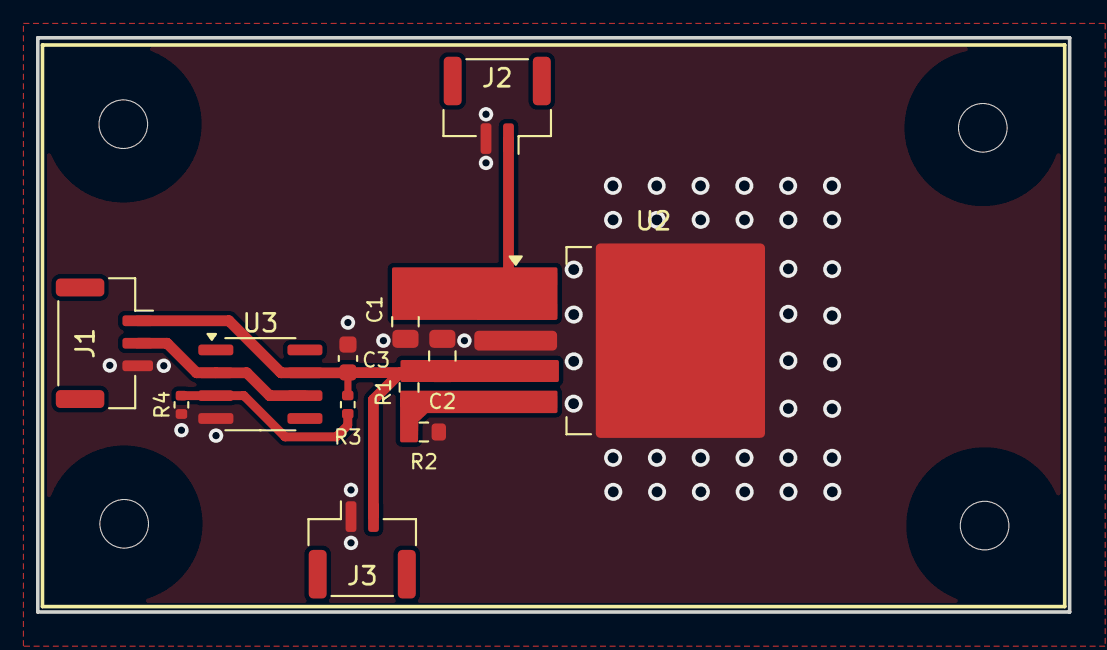
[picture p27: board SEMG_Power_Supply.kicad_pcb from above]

Board: 2 copper layers, 57.3 x 31.9 mm, 16 parts (0 on the bottom side), 6 nets.

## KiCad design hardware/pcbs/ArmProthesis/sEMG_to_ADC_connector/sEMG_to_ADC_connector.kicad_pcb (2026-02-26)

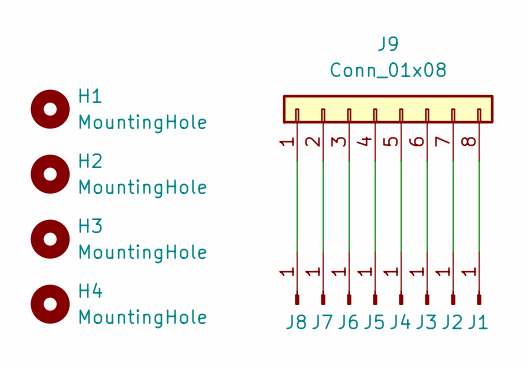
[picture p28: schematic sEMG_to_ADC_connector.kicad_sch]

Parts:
H1, H2, H3, H4: MountingHole; MountingHole_2.7mm_M2.5
J1, J2, J3, J4, J5, J6, J7, J8: Conn_01x01_Pin; DIN_Male_1PIN_1.5mm
J9: Conn_01x08; JST_GH_SM08B-GHS-TB_1x08-1MP_P1.25mm_Horizontal

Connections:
unnamed: J1.1, J9.8
unnamed: J2.1, J9.7
unnamed: J3.1, J9.6
unnamed: J4.1, J9.5
unnamed: J5.1, J9.4
unnamed: J6.1, J9.3
unnamed: J7.1, J9.2
unnamed: J8.1, J9.1

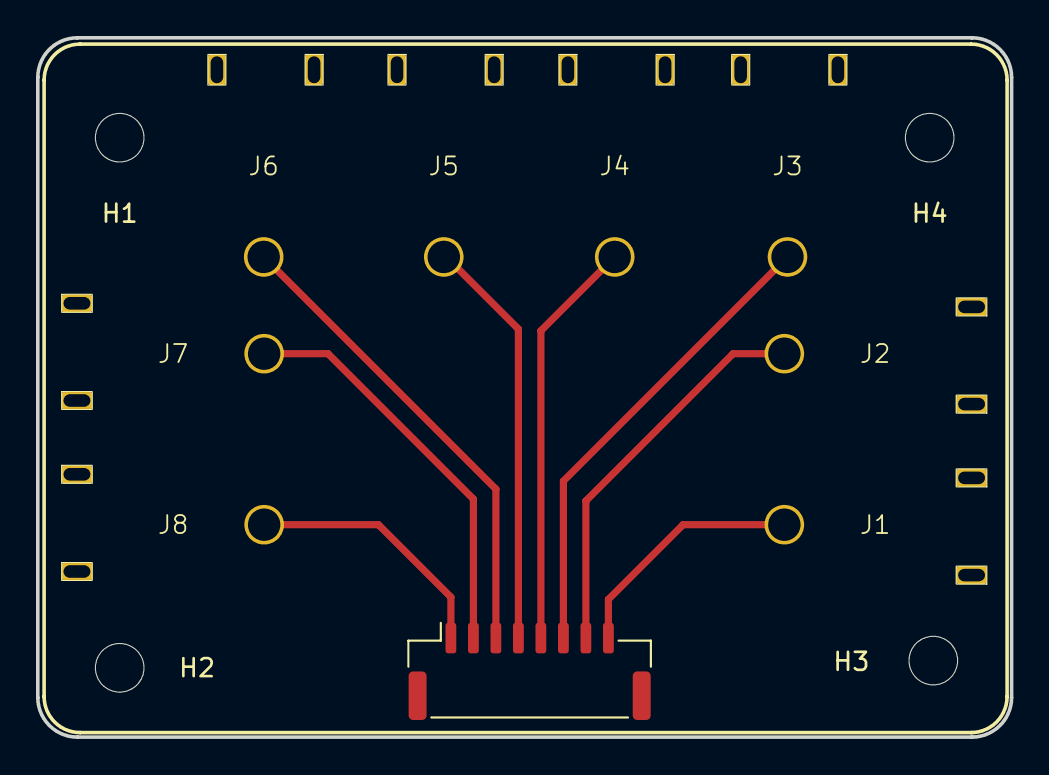
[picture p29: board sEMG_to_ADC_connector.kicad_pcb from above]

Board: 2 copper layers, 54.1 x 38.9 mm, 13 parts (0 on the bottom side), 8 nets.

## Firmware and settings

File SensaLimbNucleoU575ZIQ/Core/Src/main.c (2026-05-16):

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
/* Includes ------------------------------------------------------------------*/
#include "main.h"
#include "gpdma.h"
#include "icache.h"
#include "usart.h"
#include "gpio.h"

/* USER CODE BEGIN Includes */
#include "ad7606.h"
#include "control_loop.h"

/* USER CODE END Includes */


void SystemClock_Config(void);
static void SystemPower_Config(void);
/**
  * @brief  The application entry point.
  * @retval int
  */
int main(void)
{

  /* MCU Configuration--------------------------------------------------------*/

  /* Reset of all peripherals, Initializes the Flash interface and the Systick. */
  HAL_Init();

  /* Configure the System Power */
  SystemPower_Config();

  /* Configure the system clock */
  SystemClock_Config();

  /* Initialize all configured peripherals */
  MX_GPIO_Init();
  MX_GPDMA1_Init();
  MX_ICACHE_Init();
  MX_USART1_UART_Init();
  /* USER CODE BEGIN 2 */
#if AD7606_FORCE_FAKE
  for (int i = 0; i < 2; i++) {
    HAL_GPIO_TogglePin(LD1_GPIO_Port, LD1_Pin);
    HAL_Delay(1000);
    HAL_GPIO_TogglePin(LD1_GPIO_Port, LD1_Pin);
    HAL_Delay(1000);
  }
#else
  for (int i = 0; i < 2; i++) {
    HAL_GPIO_TogglePin(LD2_GPIO_Port, LD2_Pin);
    HAL_Delay(2500);
    HAL_GPIO_TogglePin(LD2_GPIO_Port, LD2_Pin);
    HAL_Delay(2500);
  }
#endif
  control_init();

  /* USER CODE END 2 */

  /* Infinite loop */
  /* USER CODE BEGIN WHILE */
  while (1)
  {
    /* USER CODE END WHILE */

    /* USER CODE BEGIN 3 */
    control_tick();
  }
  /* USER CODE END 3 */
}

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
/**
  * @brief  Period elapsed callback in non blocking mode
  * @note   This function is called  when TIM17 interrupt took place, inside
  * HAL_TIM_IRQHandler(). It makes a direct call to HAL_IncTick() to increment
  * a global variable "uwTick" used as application time base.
  * @param  htim : TIM handle
  * @retval None
  */
void HAL_TIM_PeriodElapsedCallback(TIM_HandleTypeDef *htim)
{
  /* USER CODE BEGIN Callback 0 */
  if (htim->Instance == TIM17) {
    control_on_sample_tick_isr();
  }
  /* USER CODE END Callback 0 */
  if (htim->Instance == TIM17)
  {
    HAL_IncTick();
  }
}

/**
  * @brief  This function is executed in case of error occurrence.
  * @retval None
  */
void Error_Handler(void)
{
  /* USER CODE BEGIN Error_Handler_Debug */
  /* User can add his own implementation to report the HAL error return state */
  __disable_irq();
  while (1)
  {
  }
  /* USER CODE END Error_Handler_Debug */
}
#ifdef USE_FULL_ASSERT
/**
  * @brief  Reports the name of the source file and the source line number
  *         where the assert_param error has occurred.
  * @param  file: pointer to the source file name
  * @param  line: assert_param error line source number
  * @retval None
  */
void assert_failed(uint8_t *file, uint32_t line)
{
  /* USER CODE BEGIN 6 */
  /* User can add his own implementation to report the file name and line number,
     ex: printf("Wrong parameters value: file %s on line %d\r\n", file, line) */
  /* USER CODE END 6 */
}
#endif /* USE_FULL_ASSERT */

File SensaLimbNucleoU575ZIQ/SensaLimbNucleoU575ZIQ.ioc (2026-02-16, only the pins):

Mcu.UserName=STM32U575ZITxQ
PA10.Signal=USART1_RX
PA9.Signal=USART1_TX

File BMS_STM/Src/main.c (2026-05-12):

/**
 ******************************************************************************
 * @file    main.c
 * @brief   BMS STM32C011F6P main application
 *
 *   I2C1  SCL = PB6   SDA = PB7  (AF6)  — BQ76905
 *   USART2 TX = PA2               (AF1)  — Nucleo UART (TX-only)
 *   ALERT# = PA8  (EXTI line 8, falling edge) — BQ alert interrupt
 ******************************************************************************
 */

#include "main.h"
#include "bq.h"

I2C_HandleTypeDef  hi2c1;
UART_HandleTypeDef huart2;

static void SystemClock_Config(void);
static void MX_GPIO_Init(void);
static void MX_I2C1_Init(void);
static void MX_USART1_UART_Init(void);

int main(void)
{
    HAL_Init();
    SystemClock_Config();
    MX_GPIO_Init();
    MX_I2C1_Init();
    MX_USART1_UART_Init();

    bq_ctx_t ctx = {0};
    ctx.nucleo_uart        = &huart2;
    ctx.nucleo_max_payload = 16;
    ctx.nucleo_timeout_ms  = 50;

    bq_init(&ctx, &hi2c1, BQ_I2C_ADDR_7B, false, 50);
    bms_init();

    for (;;)
    {
        bms_process();
        HAL_Delay(10);
    }
}

static void SystemClock_Config(void)
{
    RCC_OscInitTypeDef RCC_OscInitStruct = {0};
    RCC_ClkInitTypeDef RCC_ClkInitStruct = {0};

    RCC_OscInitStruct.OscillatorType      = RCC_OSCILLATORTYPE_HSI;
    RCC_OscInitStruct.HSIState            = RCC_HSI_ON;
    RCC_OscInitStruct.HSIDiv              = RCC_HSI_DIV1;
    RCC_OscInitStruct.HSICalibrationValue = RCC_HSICALIBRATION_DEFAULT;
    if (HAL_RCC_OscConfig(&RCC_OscInitStruct) != HAL_OK)
        Error_Handler();

    RCC_ClkInitStruct.ClockType      = RCC_CLOCKTYPE_HCLK | RCC_CLOCKTYPE_SYSCLK
                                     | RCC_CLOCKTYPE_PCLK1;
    RCC_ClkInitStruct.SYSCLKSource   = RCC_SYSCLKSOURCE_HSI;
    RCC_ClkInitStruct.SYSCLKDivider  = RCC_SYSCLK_DIV1;
    RCC_ClkInitStruct.AHBCLKDivider  = RCC_HCLK_DIV1;
    RCC_ClkInitStruct.APB1CLKDivider = RCC_APB1_DIV1;
    if (HAL_RCC_ClockConfig(&RCC_ClkInitStruct, FLASH_LATENCY_1) != HAL_OK)
        Error_Handler();
}

static void MX_I2C1_Init(void)
{
    hi2c1.Instance              = I2C1;
    hi2c1.Init.Timing           = 0x00503D5A;
    hi2c1.Init.OwnAddress1      = 0;
    hi2c1.Init.AddressingMode   = I2C_ADDRESSINGMODE_7BIT;
    hi2c1.Init.DualAddressMode  = I2C_DUALADDRESS_DISABLE;
    hi2c1.Init.OwnAddress2      = 0;
    hi2c1.Init.OwnAddress2Masks = I2C_OA2_NOMASK;
    hi2c1.Init.GeneralCallMode  = I2C_GENERALCALL_DISABLE;
    hi2c1.Init.NoStretchMode    = I2C_NOSTRETCH_DISABLE;
    if (HAL_I2C_Init(&hi2c1) != HAL_OK)
        Error_Handler();
    HAL_I2CEx_ConfigAnalogFilter(&hi2c1, I2C_ANALOGFILTER_ENABLE);
    HAL_I2CEx_ConfigDigitalFilter(&hi2c1, 0);
}

static void MX_USART1_UART_Init(void)
{
    huart2.Instance          = USART2;
    huart2.Init.BaudRate     = 115200;
    huart2.Init.WordLength   = UART_WORDLENGTH_8B;
    huart2.Init.StopBits     = UART_STOPBITS_1;
    huart2.Init.Parity       = UART_PARITY_NONE;
    huart2.Init.Mode         = UART_MODE_TX;
    huart2.Init.HwFlowCtl    = UART_HWCONTROL_NONE;
    huart2.Init.OverSampling = UART_OVERSAMPLING_16;
    if (HAL_UART_Init(&huart2) != HAL_OK)
        Error_Handler();
}

static void MX_GPIO_Init(void)
{
    GPIO_InitTypeDef GPIO_InitStruct = {0};

    __HAL_RCC_GPIOA_CLK_ENABLE();
    __HAL_RCC_GPIOB_CLK_ENABLE();

    /* PA2: USART2_TX (AF1) */
    GPIO_InitStruct.Pin       = GPIO_PIN_2;
    GPIO_InitStruct.Mode      = GPIO_MODE_AF_PP;
    GPIO_InitStruct.Pull      = GPIO_NOPULL;
    GPIO_InitStruct.Speed     = GPIO_SPEED_FREQ_LOW;
    GPIO_InitStruct.Alternate = GPIO_AF1_USART2;
    HAL_GPIO_Init(GPIOA, &GPIO_InitStruct);

    /* PB6: I2C1_SCL (AF6), PB7: I2C1_SDA (AF6) */
    GPIO_InitStruct.Pin       = GPIO_PIN_6 | GPIO_PIN_7;
    GPIO_InitStruct.Mode      = GPIO_MODE_AF_OD;
    GPIO_InitStruct.Pull      = GPIO_PULLUP;
    GPIO_InitStruct.Speed     = GPIO_SPEED_FREQ_HIGH;
    GPIO_InitStruct.Alternate = GPIO_AF6_I2C1;
    HAL_GPIO_Init(GPIOB, &GPIO_InitStruct);

    /* PA8: ALERT# — EXTI falling edge input */
    GPIO_InitStruct.Pin  = GPIO_PIN_8;
    GPIO_InitStruct.Mode = GPIO_MODE_IT_FALLING;
    GPIO_InitStruct.Pull = GPIO_PULLUP;
    HAL_GPIO_Init(GPIOA, &GPIO_InitStruct);

    HAL_NVIC_SetPriority(EXTI4_15_IRQn, 0, 0);
    HAL_NVIC_EnableIRQ(EXTI4_15_IRQn);
}

void HAL_GPIO_EXTI_Falling_Callback(uint16_t GPIO_Pin)
{
    if (GPIO_Pin == GPIO_PIN_8)
        bms_alert_isr_hook();
}

void Error_Handler(void)
{
    __disable_irq();
    for (;;);
}

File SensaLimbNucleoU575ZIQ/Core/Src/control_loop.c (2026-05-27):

// Main control loop implementation.
#include "control_loop.h"

#include <stdint.h>
#include <stdio.h>
#include <stdbool.h>

#include "main.h"
#include "core_cm33.h"
#include "ad7606.h"
#include "ad7606_pins.h"
#include "UART/nucleo_uart_rx_port.h"
#include "rms_filter.h"
#include "ann_infer.h"

// Provided by stm32u5xx_it.c
void uart_dma_idle_init(UART_HandleTypeDef *huart);

extern UART_HandleTypeDef huart1;

static CircularList g_rms_lists[CHANNELS];
static float g_rms_values[CHANNELS][SAMPLE_RATE];
static float g_features[CHANNELS][SAMPLES];
static RmsFilter g_rms_filter;

static volatile uint32_t g_sample_tick = 0;
static volatile bool g_sampling_enabled = false;
static uint32_t g_last_pred_tick = 0;
static uint32_t g_last_stats_tick = 0;
static uint32_t g_last_led_tick = 0;
static uint32_t g_last_sample_tick_print = 0;

static uint32_t g_last_feat_cycles = 0;
static uint32_t g_last_ann_cycles = 0;
static uint32_t g_pred_count_1s = 0;
static uint64_t g_pred_cycles_sum_1s = 0;
static uint32_t g_pred_cycles_max_1s = 0;
static int64_t g_pred_sum_milli_1s = 0;
static int32_t g_pred_min_milli_1s = 0;
static int32_t g_pred_max_milli_1s = 0;
static volatile float g_angle_history_deg = 0.0f;
#define ANGLE_HISTORY_LAG_SAMPLES 100u
#define ANGLE_CTX_RING_LEN (SAMPLE_RATE + ANGLE_HISTORY_LAG_SAMPLES + 16u)
static float g_angle_ctx_ring[ANGLE_CTX_RING_LEN];
static float g_angle_ctx_window[SAMPLES];

static float angle_ctx_ring_get(uint32_t sample_idx) {
    return g_angle_ctx_ring[sample_idx % ANGLE_CTX_RING_LEN];
}

static void debug_print_pred_stats(void) {
    if (g_pred_count_1s == 0u) {
        return;
    }
    uint32_t avg_cycles = (uint32_t)(g_pred_cycles_sum_1s / g_pred_count_1s);
    uint32_t avg_us = (uint32_t)(((uint64_t)avg_cycles * 1000000ULL) / SystemCoreClock);
    uint32_t max_us = (uint32_t)(((uint64_t)g_pred_cycles_max_1s * 1000000ULL) / SystemCoreClock);
    int32_t avg_pred_milli = (int32_t)(g_pred_sum_milli_1s / (int64_t)g_pred_count_1s);
    int32_t avg_whole = avg_pred_milli / 1000;
    int32_t avg_frac = avg_pred_milli % 1000;
    if (avg_frac < 0) {
        avg_frac = -avg_frac;
    }
    int32_t min_whole = g_pred_min_milli_1s / 1000;
    int32_t min_frac = g_pred_min_milli_1s % 1000;
    if (min_frac < 0) {
        min_frac = -min_frac;
    }
    int32_t max_whole = g_pred_max_milli_1s / 1000;
    int32_t max_frac = g_pred_max_milli_1s % 1000;
    if (max_frac < 0) {
        max_frac = -max_frac;
    }
    char buf[160];
    int n = snprintf(buf, sizeof(buf),
                     "pred/s=%lu avg_pred=%ld.%03ld min=%ld.%03ld max=%ld.%03ld avg=%lu cycles (%lu us) max=%lu us\r\n",
                     (unsigned long)g_pred_count_1s,
                     (long)avg_whole, (long)avg_frac,
                     (long)min_whole, (long)min_frac,
                     (long)max_whole, (long)max_frac,
                     (unsigned long)avg_cycles,
                     (unsigned long)avg_us,
                     (unsigned long)max_us);
    if (n > 0) {
        HAL_UART_Transmit(&huart1, (uint8_t *)buf, (uint16_t)n, 10);
    }
}

static void debug_print_sample_rate(uint32_t sample_tick) {
    uint32_t delta = sample_tick - g_last_sample_tick_print;
    g_last_sample_tick_print = sample_tick;
    char buf[64];
    int n = snprintf(buf, sizeof(buf), "samples/s=%lu\r\n", (unsigned long)delta);
    if (n > 0) {
        HAL_UART_Transmit(&huart1, (uint8_t *)buf, (uint16_t)n, 10);
    }
}

static void dwt_init(void) {
    CoreDebug->DEMCR |= CoreDebug_DEMCR_TRCENA_Msk;
    DWT->CYCCNT = 0;
    DWT->CTRL |= DWT_CTRL_CYCCNTENA_Msk;
}

void control_init(void) {
    dwt_init();
    ad7606_init();

    uart_dma_idle_init(&huart1);
    ann_init();

    for (size_t i = 0; i < CHANNELS; i++) {
        circular_list_init(&g_rms_lists[i], RMS_WINDOW);
    }

    rms_filter_init(&g_rms_filter,
                    CHANNELS,
                    SAMPLE_RATE,
                    RMS_WINDOW,
                    RMS_DOWNSAMPLE,
                    g_rms_lists,
                    g_rms_values,
                    g_features);
    control_enable_sampling();
}

static volatile uint16_t g_last_raw_sample[2] = {0};

void control_on_sample_tick_isr(void) {
    if (!g_sampling_enabled) {
        return;
    }
    uint16_t sample[CHANNELS];
    ad7606_read_all_channels(sample, CHANNELS);
    rms_filter_update(&g_rms_filter, sample);
    g_sample_tick++;
    g_angle_ctx_ring[g_sample_tick % ANGLE_CTX_RING_LEN] = g_angle_history_deg;

    g_last_raw_sample[0] = sample[0];
    g_last_raw_sample[1] = sample[1];
}

void control_enable_sampling(void) {
    g_sampling_enabled = true;
}

void control_tick(void) {
    uint32_t sample_tick = g_sample_tick;

    if (sample_tick >= (SAMPLE_RATE + ANGLE_HISTORY_LAG_SAMPLES) &&
        rms_filter_ready(&g_rms_filter) &&
        ((uint32_t)(sample_tick - g_last_pred_tick) >= 50u)) {
        g_last_pred_tick = sample_tick;

        uint32_t t0 = DWT->CYCCNT;
        __disable_irq();
        rms_filter_build_features(&g_rms_filter);
        uint32_t window_start = sample_tick - SAMPLE_RATE;
        for (size_t j = 0; j < SAMPLES; j++) {
            uint32_t block_start = window_start + (uint32_t)(j * RMS_DOWNSAMPLE);
            float sum = 0.0f;
            for (size_t k = 0; k < RMS_DOWNSAMPLE; k++) {
                uint32_t idx = block_start + (uint32_t)k;
                sum += angle_ctx_ring_get(idx - ANGLE_HISTORY_LAG_SAMPLES);
            }
            g_angle_ctx_window[j] = sum / (float)RMS_DOWNSAMPLE;
        }
        __enable_irq();
        g_last_feat_cycles = DWT->CYCCNT - t0;

        t0 = DWT->CYCCNT;
        float pred = ann_predict_with_history(&g_features[0][0], CHANNELS, SAMPLES, g_angle_ctx_window, SAMPLES);
        g_last_ann_cycles = DWT->CYCCNT - t0;
        if (pred < 0.0f) {
            pred = 0.0f;
        } else if (pred > 160.0f) {
            pred = 160.0f;
        }
        g_angle_history_deg = pred;
        uint32_t pred_cycles = g_last_feat_cycles + g_last_ann_cycles;
        g_pred_cycles_sum_1s += pred_cycles;
        if (pred_cycles > g_pred_cycles_max_1s) {
            g_pred_cycles_max_1s = pred_cycles;
        }
        g_pred_count_1s++;
        int32_t pred_milli = (int32_t)(pred * 1000.0f);
        g_pred_sum_milli_1s += pred_milli;
        if (g_pred_count_1s == 1u) {
            g_pred_min_milli_1s = pred_milli;
            g_pred_max_milli_1s = pred_milli;
        } else {
            if (pred_milli < g_pred_min_milli_1s) {
                g_pred_min_milli_1s = pred_milli;
            }
            if (pred_milli > g_pred_max_milli_1s) {
                g_pred_max_milli_1s = pred_milli;
            }
        }

        // motor logic here
        // if (movement_changed(pred)) {
        //     motor_set_angle(pred);
        // }
    }

    nucleo_uart_rx_port_process();
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

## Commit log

2025-09-12 Voltage supply of sEMG & ADC
    [AD7606.kicad_sch, BMS.kicad_pcb, BlockDiagram_ArmProthesis.kicad_sch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]
2025-09-14 EMG sensor v0.2
    [EMG sensors.kicad_pcb]
2025-09-18 sEMG sensors v0.3
    [EMG sensors.kicad_pcb, EMG sensors.kicad_sch]
2025-09-18 Fixes
    sEMG - minor
    Voltage supply... - major but not fixed
    [EMG sensors.kicad_pcb, Voltage supply of sEMG & ADC.kicad_pcb]
2025-09-18 Additional to last push
    [Voltage supply of sEMG & ADC.kicad_pcb]
2025-09-18 Voltage supply sEMG & ADC v0.2
    Major fixes. Mounting holes missing
    [Voltage supply of sEMG & ADC.kicad_pcb]
2025-09-21 BMS v0.2v + polishment of Vsupply board
    [BMS.kicad_pcb, BMS.kicad_sch, Voltage supply of sEMG & ADC.kicad_pcb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]
2025-09-21 Connector update of the sEMG sensor
    Changed it to be JST_GH_SM04B instead of JST_GH_BM04B for easier use
    [EMG sensors.kicad_pcb, EMG sensors.kicad_sch]
2025-09-22 ADC + sEMG changes
    sEMG - connector updates
    ADC - major changes - connectors, layout changes
    [ADC.kicad_pcb, ADC.kicad_sch, EMG sensors.kicad_pcb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]
2025-09-23 BMS v0.3 + main folder reconstruction
    [ADC.kicad_pcb, ADC.kicad_sch, BMS.kicad_pcb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]
2025-09-23 sEMG critical issue
    Corrected inaccurate DIN 1.5mm jack footprint
    [BMS.kicad_pcb, EMG sensors.kicad_pcb]
2025-09-23 Cosmetics xd
    [EMG sensors.kicad_pcb, Voltage supply of sEMG & ADC.kicad_pcb]
2025-10-27 Vs of sEMG and ADC v0.4
    [Voltage supply of sEMG & ADC.kicad_pcb]
2025-11-03 Corrected BMS connection
    [BMS.kicad_pcb, BMS.kicad_sch]
2025-11-04 BMS v0.5 still not resized
    [BMS.kicad_pcb, BMS.kicad_sch, Voltage supply of sEMG & ADC.kicad_pcb]
2026-01-13 Mendeley data set + plotter
    Analyzing data sets and beginning to develop the ML algorithm for the arm
    [record-[2014.12.5-15.18.59].csv, record-[2014.12.5-15.19.19].csv, record-[2014.12.5-15.48.34].csv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]
2026-01-13 Normalizer + plotter(upgraded
    Normalizer for the data.
    Plotter has new functionalities such as - plot all subjects data and distribute them to new folders, calculate db/frequency for a new plot etc.
    [record-[2014.12.5-15.18.59]_normalized.csv, record-[2014.12.5-15.19.19]_normalized.csv, record-[2014.12.5-15.48.34]_normalized.csv]
2026-01-19 Fix Vsupply
    added important Schottky diodes on the BUCK
    [Voltage supply of sEMG & ADC 2.0.csv, Voltage supply of sEMG & ADC 2.0.kicad_pcb, Voltage supply of sEMG & ADC 2.0.kicad_sch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]
2026-01-19 New
    Mendeley dataset is not good enough for angle regression or for 3 class classifier.
    Moved on to Toro Ossaba's dataset specifically designed for training ML algorithms - smooth kinetic transitions.
    Trainers for several ML models have been implemented but the most successful one is conv1d_angle_toro_ossaba. This exact model doesn't extract features but lets the model extrarct them by 3 convolutional layers. For best accuracy history angle around 0.1s before the new prediction must be parsed too.
    [record-[2014.12.5-15.18.59]_normalized.csv, record-[2014.12.5-15.19.19]_normalized.csv, record-[2014.12.5-15.48.34]_normalized.csv]
2026-01-20 Fixed EMG sensors active band pass filter
    [EMG sensors.kicad_sch, Voltage supply of sEMG & ADC 2.0.kicad_pcb, Voltage supply of sEMG & ADC 2.0.kicad_sch]
2026-01-20 new LDO with a proper rail splitter
    [Voltage supply of sEMG & ADC 2.0.kicad_pcb, Voltage supply of sEMG & ADC 2.0.kicad_sch]
2026-01-21 Fixed LCSC numbers of the new filter parts
    [EMG sensors.kicad_sch]
2026-01-24 Fixed compatibility of connectors + new BMS chip
    [ADC.kicad_pcb, BMS.kicad_pcb, BMS.kicad_sch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]
2026-01-24 bms V0.7 with BQ76905
    [BMS.kicad_pcb, BMS.kicad_sch]
2026-01-28 BMS board fixes
    [BMS.kicad_sch]
2026-02-01 Ordered versions
    [ADC(1).PcbDoc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]
2026-02-05 Configure BQ76905 protections and alert handling
    Add concrete DM config values for alarms, enabled protections, and FET trip mapping, plus ADSCAN-based CUV/COV delay calculation and SCD delay placeholder.
    Implement full alert decision flow: status-first handling, XDSG timeout adjustment, fault bookkeeping, low-battery percent polling/warning, and Nucleo action hooks/stubs.
2026-02-06 Finalize BMS config, alert actions, and UART framing
    Add concrete DM configuration (alarm mask, protection enables, FET trip mapping, CUV/COV thresholds/delays/hysteresis, SCD code) and reliable CFGUPDATE init with FET enable and alarm clear.
    Implement full alert/status handling with last-fault reporting/retry, low-batt percent polling, and UART framing (seq + CRC8).
2026-02-06 Moved the files to the correct folder
    Apparently I have been working outside of the BMS-STM folder without realizing it...
    [bq.c, bq.h]
2026-02-06 UART RX implementation with empty action functions
2026-02-06 Add AD7606 driver and relocate UART RX code
    Introduce AD7606 parallel read scaffolding with DWT timing helpers.
    Move UART RX implementation into NUCLEO/UART and remove old paths.
2026-02-09 Main function reallocated + down sampling logic fixed
    [ad7606.c, main.c]
2026-02-09 UART DMA + IDLE interrupt integration template.
2026-02-10 Refactor control loop and add ML assets
    Split sampling/RMS/ANN logic into dedicated modules and simplify main loop.
    Implemented the correct flow for reading the samples, processing them into input vectors for the ANN.
    The exact function for parsing those inputs into the ANN are still not implemented.
    Add ML models/assets folder used for prosthesis inference workflows.
    [record-[2014.12.5-15.18.59].csv, record-[2014.12.5-15.18.59]_normalized.csv, record-[2014.12.5-15.19.19].csv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]
2026-02-16 Retrained several models and changed input layer
    Newer models now accept 3x200 samples instead of 205.
    [emg_1000.csv]
2026-02-16 wire UART DMA + fake ADC data path + STM32 project architecture
    Move the nucleo app sources into the STM32 project layout, hook the control
    loop into main, and add UART DMA/IDLE RX processing. Add a fake ADC data
    table path to test RMS → ANN parsing without hardware.
2026-02-23 Sync latest Nucleo firmware and timing architecture.
    Integrate ISR-based 1 kHz sampling with 50 ms rolling-window inference, stabilize UART/diagnostic logging, and align project/docs with the current STM32U575 workflow and fake-data validation path.
    [ad7606.c, control_loop.c]
2026-02-26 Remove unrelated KiCad projects after import
    The original KiCad repo contained multiple projects; keep only SensaLimb-related boards under hardware/pcbs.
    [AD7606.kicad_pcb, AD7606.kicad_sch, BMS.kicad_pcb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]
2026-02-26 Clean old/unused Gerbers and backup files from KiCad project
    [ADC-B_Cu.gbr, ADC-B_Mask.gbr, ADC-B_Paste.gbr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]
2026-02-26 Synced the files with the latest versions
    The files that were merged were one version behind. Also the names of the projects were renamed for clarity.
    [ADC.csv, ADC.kicad_pcb, ArmProthesis.kicad_sch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]
2026-02-27 Cleared zip backup folders + old boms
    [BlockDiagram_ArmProthesis.kicad_pcb, BlockDiagram_ArmProthesis.kicad_sch, emg_1000.csv]
2026-02-27 Align angle-history preprocessing with ML training pipeline
    Switch context-angle generation to a 1 kHz ring buffer, apply a 0.1 s lag at sample level, and downsample to 200 Hz per inference window. Also align ANN angle normalization/de-normalization with trai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
2026-05-12 BMS_STM STM32C011F6Px project setup
    Set up a bare STM32CubeIDE project for the BMS MCU (STM32C011F6Px) targeting the BQ76905 2-cell BMS IC. Configured I2C1 (PB6/PB7) for BQ76905 communication, USART2 (PA2) for TX logging to the Nucleo,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
2026-05-12 Removed old and unused dataset from repo
    [record-[2014.12.10-10.14.31].csv, record-[2014.12.10-10.14.31]_normalized.csv, record-[2014.12.10-10.6.46].csv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]
2026-05-16 Enable VddIO2 for port G - fixes DB7/DB8
    [ad7606.c, ad7606_pins.h, control_loop.c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]
2026-05-17 Add RESET pulse, CS/RD debug mode, ISR UART fix, RESET pin PD4
    [ad7606.c, ad7606_pins.h]
2026-05-18 fix(ad7606): correct ADC control pin assignments — restore conversions
    The AD7606 was not converting due to three independent pin-assignment
    faults, all rooted in pins being assigned without checking existing
    board/silicon functions.
    CONVST (was PC13 -> now PE3)
    PC13 is a backup-domain pin with weak drive; it produced a 10-12us
    RC-curve rising edge instead of a sharp digital edge, so the AD7606
    never received a valid conversion trigger. Backup-domain config
    survives resets/reflashes, which is why a firmware revert never fixed
    it. Moved to PE3 (standard GPIO), init as OUTPUT_PP / VERY_HIGH speed,
    idle high.
    STBY (was PB7 -> now <new pin>)
    PB7 is the Nucleo LD2 LED. MX_GPIO_I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
    [ad7606.c, ad7606_pins.h]
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

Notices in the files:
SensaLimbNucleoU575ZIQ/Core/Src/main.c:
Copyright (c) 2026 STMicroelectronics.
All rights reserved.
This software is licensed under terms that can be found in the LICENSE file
